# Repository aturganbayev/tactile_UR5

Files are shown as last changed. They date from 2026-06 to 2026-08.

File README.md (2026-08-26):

# Tactile UR5

Automated tactile exploration of silicone breast phantoms ("eggs") using a UR5 robot arm, aiming to **locate an embedded hard "tumor" ball from touch alone**. The pipeline extracts surface geometry from a CAD model, calibrates it to the robot's coordinate frame via ICP, generates approach/press poses over the surface, executes them on the physical (or simulated) robot over a raw URScript TCP socket, and records the contact force (ATI Nano17) synchronized with the TCP pose for each press.

```
cone.STL → surface points → ICP calibration → touch poses → robot execution → force+pose recording
```

Two sensing approaches share that pipeline and are kept deliberately separate:
the **ATI Nano17** on the end-effector pressing the phantom (above), and a
**XELA uSkin tactile pad** on the end-effector recording raw tactile counts
([see below](#xela-tactile-skin-separate-approach)). They have their own pose
grids, recorders and analysis; neither modifies the other.

---

## Hardware

| Component | Details |
|---|---|
| Robot | Universal Robots UR5 (CB2 controller, PolyScope 1.x) |
| Tool | Silicone breast phantom tactile sensor ("egg"), some with an embedded hard ball |
| Tool tip offset | 86 mm along TCP +Z axis |
| Force sensor | ATI Nano17 (SI-50-0.5), serial `FT12876` |
| Force DAQ | NI-DAQ, read via pyForceDAQ (`nidaqmx` backend) |
| Real robot IP | `192.168.0.110` (set as `REAL_HOST` in `pose_utils.py`) |
| Simulation IP | `172.17.0.2` (URSim Docker) |
| Touch-program port | `30002` (secondary client) — used by `run_side_strip_poses.py` so the streamed program does **not** suspend the state broadcast |
| Command / state port | `30003` (single moves like home/start/stop, and the 125 Hz TCP-pose stream the recorder reads) |

---

## Setup

The workstation dependencies are pinned in `requirements.txt`. The `cad_env/`
virtualenv is **not** tracked in git — recreate it from the requirements file:

```bash
# Create and activate the virtualenv, then install dependencies
python3 -m venv cad_env
source cad_env/bin/activate
pip install -r requirements.txt
```

On later sessions just activate it:

```bash
source cad_env/bin/activate
```

**DAQ PC only** — the force + pose recorder in `pyForceDAQ/` additionally needs
`nidaqmx` and `psutil` (uncomment them in `requirements.txt`), the NI-DAQmx
system driver, and `atidaq.so` built from `pyForceDAQ/atidaq_cdll/`. See the
[Force + pose data collection](#force--pose-data-collection-pyforcedaq) section.

### Starting URSim (simulation)

The simulation IP (`172.17.0.2`, `SIM_HOST` in `pose_utils.py`) is the Docker
container's own bridge-network IP, not a host port — so it only matches if
this is the **first** container started on the default bridge network. Start
it, then power it on and release the brakes (also doable through the
PolyScope GUI at `http://localhost:6080/vnc.html`, no VNC client needed):

```bash
docker run --rm -d -p 5900:5900 -p 6080:6080 --name ursim universalrobots/ursim_e-series:latest

# Power on + release brakes via the dashboard server (or click through the
# same steps in the noVNC viewer above):
python3 - <<'EOF'
import socket, time
s = socket.create_connection(("172.17.0.2", 29999), timeout=5)
s.recv(4096)
s.sendall(b"power on\n"); time.sleep(3); print(s.recv(4096))
s.sendall(b"brake release\n"); time.sleep(3); print(s.recv(4096))
EOF
```

If another container already holds `172.17.0.2` (check with
`docker inspect -f '{{json .NetworkSettings.Networks.bridge.IPAddress}}' <name>`
for each container in `docker ps`), start this one on different host ports
(e.g. `-p 5901:5900 -p 6081:6080`) — the internal control ports (30001-30004,
29999) aren't published to the host at all, only reachable via the
container's own bridge IP, so host-port conflicts don't affect the robot
scripts, only the VNC viewer.

---

## Project structure

Scripts are grouped by pipeline stage. Every script resolves data files through
`paths.py`, so they can be run from any working directory (e.g.
`python pose_generation/generate_side_strip_poses.py` from the repo root).

```
tactile_UR5/
├── paths.py              # central path config (single source of truth)
├── pose_utils.py         # shared geometry + motion parameters
├── geometry/             # extract_points.py  (STL → surface points)
├── ur_calibration/       # ICP calibration scripts + their artifacts
├── pose_generation/      # generate_side_strip_poses.py  (surface points → touch poses)
├── execution/            # run_*.py + robot move/stop scripts
├── cone_plots/           # STL point-cloud / normals visualisation
├── pyForceDAQ/            # force + pose recording (ATI Nano17) and press-data analysis
│   └── cone_data/         # sync_cone_data.sh landing spot (gitignored)
├── ur5_tactile_data/      # per-egg recordings + analysis batch scripts (see below)
├── Xela_sensor/           # second, independent sensor approach (see below) - XELA uSkin tactile skin
│   └── palpation/         # pad-based palpation recorder + pose generator
├── data/                  # cone.STL + generated pose CSVs + fixture/mount CAD files
└── figures/               # plot outputs from the CAD/pose pipeline (steps 1-6)
```

---

## Pipeline

### Step 1 — Extract surface points from STL

Samples 3000 points (with surface normals) from the cone CAD model.

```bash
python geometry/extract_points.py
```

**Input:** `data/cone.STL`  
**Output:** `data/surface_points.csv` — columns: `x, y, z, nx, ny, nz` (in mm, STL frame)

---

### Step 2 — (Optional) Visualise the point cloud

```bash
# Plot sampled surface points
python cone_plots/cone_plot.py

# Plot surface points with corrected outward normals
python cone_plots/cone_plot_normals.py
```

**Outputs:** `figures/surface__points_cone_plot.png`, `figures/surface__points_cone_normals_plot.png`

| Point cloud | Surface normals |
|---|---|
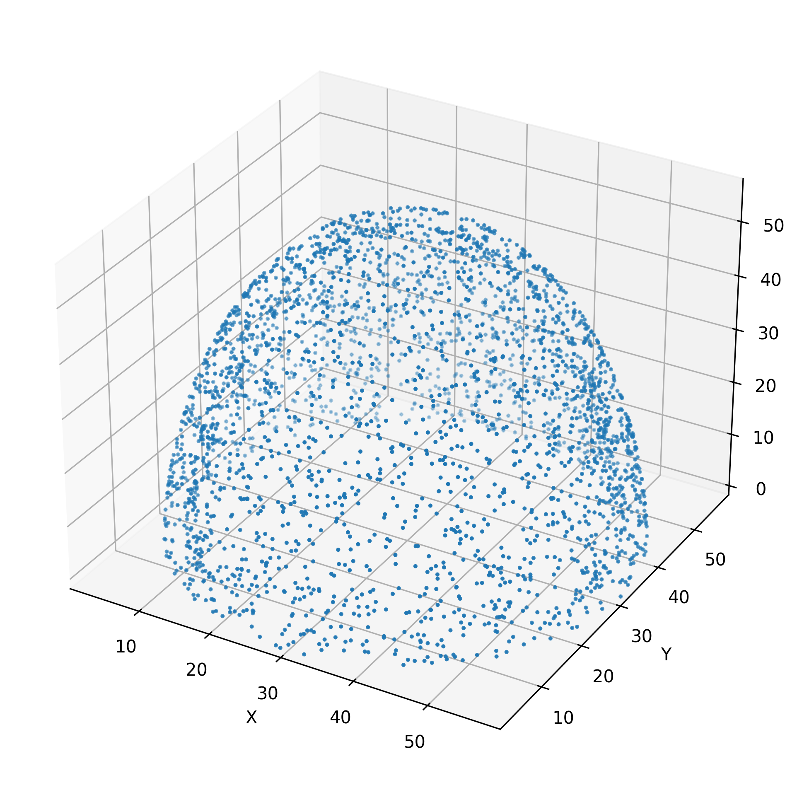
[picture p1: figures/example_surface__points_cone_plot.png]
Surface point cloud
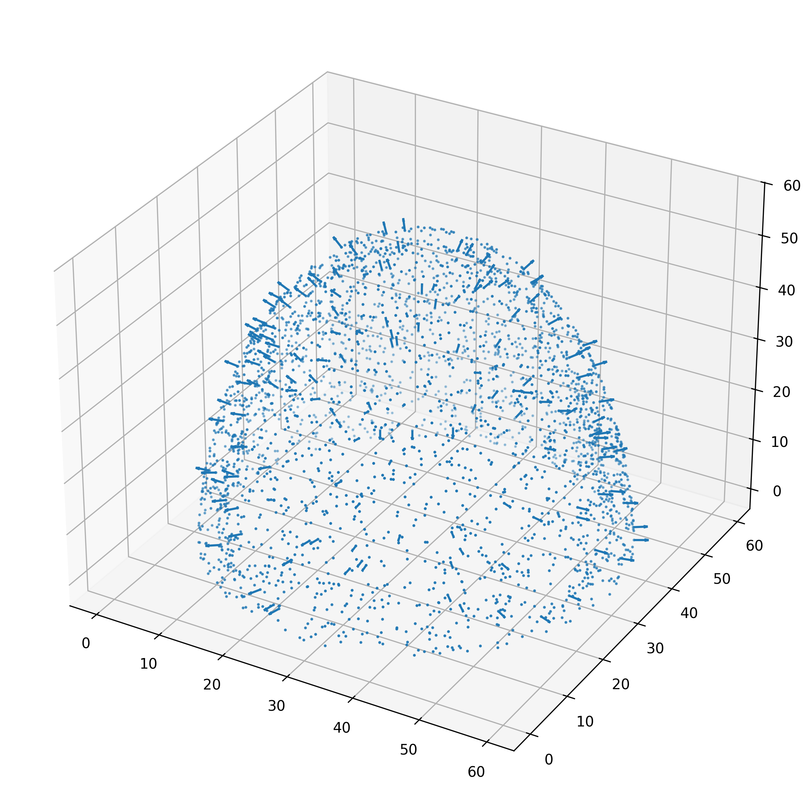
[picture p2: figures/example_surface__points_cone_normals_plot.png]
Surface normals
|  |  |

---

### Step 3 — Record physical calibration points

Interactive CLI. Move the robot so the sensor tip physically touches the cone and read the TCP pose from the teach pendant for each point.

```bash
python ur_calibration/record_icp_points.py
```

- **Point 1 must be the cone apex** (top).
- Record 10–15 more points spread around the upper sides.
- Enter each pose as `x y z rx ry rz` (mm or m — auto-detected; radians for rotation).
- Type `done` when finished.

**Output:** `ur_calibration/physical_points.csv` — columns: `x_tcp, y_tcp, z_tcp, rx, ry, rz, x, y, z`

---

### Step 4 — Run ICP calibration

Aligns the STL point cloud to the robot base frame using the physical touch points as ground truth.

```bash
python ur_calibration/calibrate_icp.py
```

**Constrained to a vertical axis.** The calibration **pins the cone axis to the robot base +Z** and fits only the position (translation-only ICP). The reason: the calibration touch points all sit near the apex (top ~half of the cone), which barely constrains the axis *orientation* — a free ICP latches onto noise and produces a spurious ~20° tilt, making an upright cone look leaning in the base frame. Since the cone physically stands upright on a level surface, fixing the axis vertical removes that artifact and actually fits the points slightly better (RMS ≈ 2.2 mm vs 2.5 mm for the free fit on the original dataset; a careful 13-point recalibration reaches ~1.5 mm RMS). Rotation about the vertical is irrelevant for a surface of revolution, so it is left at identity.

> This assumes the robot base is mounted vertical and the cone sits on a level surface. If your base is genuinely tilted, restore a free ICP instead.

**Inputs:** `data/surface_points.csv`, `ur_calibration/physical_points.csv`, `data/cone.STL`  
**Outputs:**
- `ur_calibration/icp_transformation_matrix.txt` — 4×4 STL-to-robot transform (rotation = identity, i.e. cone upright)
- `ur_calibration/surface_points_base.csv` — surface points (with normals) in robot base frame (meters)

Calibration quality (mean/RMS/max error in mm) is printed on completion. Target: mean error < 5 mm.

---

### Step 5 — Validate calibration

Re-checks alignment by projecting recorded physical contact points onto the calibrated mesh.

```bash
python ur_calibration/validate_calibration.py
```

**Inputs:** `ur_calibration/physical_points.csv`, `ur_calibration/icp_transformation_matrix.txt`, `ur_calibration/surface_points_base.csv`  
Re-run `ur_calibration/calibrate_icp.py` if mean error exceeds 5 mm.

---

### Step 6 — Generate touch poses

Generates `NUM_STRIPS` vertical strips evenly distributed around the cone, each with `NUM_POINTS` touch points from near the apex down to `MIN_HEIGHT_FRACTION` of the cone height. All work is done in the cone's own axis frame (the vertical axis established during calibration). This is the only pose generator in the pipeline — pressing every one of the ~3000 sampled surface points isn't realistic, so only the evenly-spaced strip grid is generated and executed.

Each contact point is **synthesized directly on the strip's meridian** rather than picking the nearest measured point. Because the cone is a surface of revolution, this gives:

- **Straight strips** — every point of a strip sits at exactly the strip's azimuth, so the strip traces a clean line down the cone (no zig-zag from discrete sampling).
- **Even spacing, apex included** — target heights are evenly spaced including both endpoints, so the first point of every strip lands exactly on the true apex (instead of being offset by half a band width); the local cone radius still comes from a linear fit of the points within each height band.
- **Clean normals** — the surface normal is taken from the nearest measured point, projected into the meridian plane and forced outward (handles the apex too).

To keep the printed sensor holder clear of the cone and the wrist clear of the lower arm, the tool orientation is tilted toward vertical with a height-scaled magnitude: `MIN_ORIENTATION_TILT_DEG` (7°) at the apex band up to `MAX_ORIENTATION_TILT_DEG` (14°) at the lowest band. **Only the orientation tilts** — the contact point and press direction stay on the true surface normal — so the press stays near-perpendicular (≈5–15° off-normal). The applied tilt is recorded per pose in the `tilt_deg` CSV column.

**Apex orientation matches its strip's azimuth.** At the true apex the outward normal points straight up the cone axis, so azimuth has no local meaning there. `normal_to_rotvec()` in `pose_utils.py` resolves this case with a `y_hint`: the generator passes the strip's meridian-perpendicular direction, so the apex point's frame stays consistent with every other point in its strip. Descending a strip, the tool orientation therefore changes smoothly in pitch only — azimuth is constant top to bottom.

```bash
python pose_generation/generate_side_strip_poses.py
```

**Output:** `data/cone_touch_poses.csv` (with `strip`, `strip_angle_deg`, `tilt_deg` columns), `figures/cone_touch_poses.png`

The plot has two panels: a **3D view** (robot base frame) and a **top-down view** along the cone axis (good for checking the strips are evenly distributed around the circle).

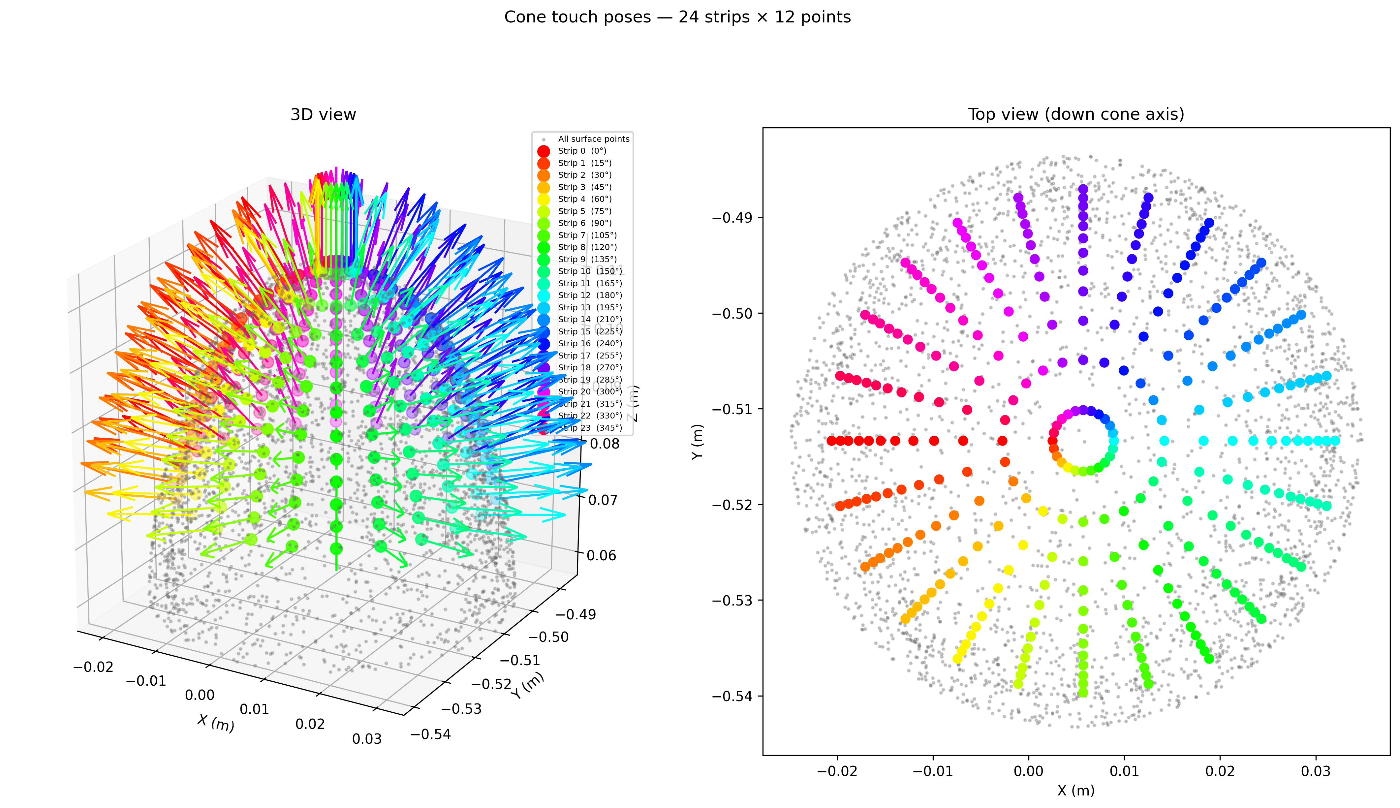
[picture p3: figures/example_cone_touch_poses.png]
Cone touch poses


Key parameters, defined as tunable constants at the top of the script (see the comments there for current defaults):

| Parameter | Description |
|---|---|
| `NUM_STRIPS` | Strips evenly distributed around the cone |
| `NUM_POINTS` | Touch points per strip (top → bottom) |
| `MIN_HEIGHT_FRACTION` | Lower bound of the strips (fraction of cone height). Lower it for more lower-cone coverage, at the cost of clearance (arm config keeps the wrist joints off the table, esp. on the near side toward the robot base). |

Both `NUM_STRIPS` and `NUM_POINTS` are free to change; the generator and executor adapt automatically. Each row in the pose CSV contains a paired approach pose (`approach_distance` = 15 mm stand-off along the surface normal) and a press pose (`press_distance` = 15 mm into the surface).

---

### Step 7 — Move robot to start pose

Moves the robot through a safe pre-pose to the hover position directly above the cone apex (30 mm clearance).

```bash
python execution/home_start.py
```

Prompts for `sim` or `real` mode. Motion sequence:

```
movej → Pre-pose [-π/2, -π/2, -π/2, -π/2, π/2, -π/2]
   └─ movel → Start pose (apex TCP + 30 mm Z)
```

To move directly to the start pose only (skipping the pre-pose joint move):

```bash
python execution/start_pose.py
```

To move to *only* the pre-pose joint configuration (skipping the movel to the
cone's start pose entirely) — e.g. as a safe, cone-independent waypoint
before positioning the robot for other work (such as the XELA calibration
rig, see below):

```bash
python execution/go_pre_pose.py
```

---

### Step 8 — Execute touch sequence

Streams the full URScript program to the robot. For each pose: transit to approach → press → retract. Prompts for `sim` or `real`. The robot returns to the start pose after all touches complete.

```bash
python execution/run_side_strip_poses.py
```

Motion strategy (`execution/run_side_strip_poses.py`):

- **Inverse kinematics is solved in software** (`ur5_ik_near` in `pose_utils.py`, validated UR5 FK/IK) for every pose, seeded from the previous solution within a strip and reset to the start config between strips — this both validates reachability (unreachable poses are flagged and skipped) and keeps a chained seed ready for the next strip's entry `movej`. The controller's `get_inverse_kin` is *not* used: it does a single Newton solve from one fixed seed, which cannot converge for poses spread all the way around the cone, leaving the arm reorienting without reaching the points.
- **Only the first point of each strip transits in joint space** (`movej([j1..j6])`) — that's the big swing from the start pose all the way around to the strip's azimuth, which needs the offline IK solve above.
- **Every other transit within a strip uses `movel`** to the precomputed Cartesian approach pose, at the slow contact speed (`*_approach_*`, same as the press itself) — consecutive points are millimetres apart and share the same azimuth (see apex-orientation note above), so a straight-line Cartesian move keeps the tool orientation locked to that azimuth the whole way.
- **Press and retract use `movel`** — short, controlled linear motion along the surface normal, at the slow contact speed (`*_approach_*` in `pose_utils.py`).
- **Between strips the tool lifts straight up** (`SAFE_LIFT_M` = 60 mm, base +Z) *before* the joint-space swing back to the start pose, so the `movej` arc cannot graze the cone (which otherwise registers a false press).
- **Settle pauses are mode-dependent** (`SETTLE`): 0.1 s in sim, 1 s on real.
- Each transit logs a **1-based** `pose`/`strip`/`point` identifier via `textmsg` (e.g. `pose 13 strip 2 point 1`) — visible in the PolyScope Log tab to identify the failing pose after a protective stop. `pose` numbering matches the 1-based press numbering `record_cone_press.py` writes, so a specific press can be traced back to the exact strip/point that produced it (the underlying `strip` column in the pose CSV itself stays 0-based).

> **Note on speeds:** `V_sim`/`A_sim`/`V_real`/`A_real` (joint speed/accel, rad/s and rad/s²) apply only to the once-per-strip entry `movej`; every within-strip transit, press, and retract moves at the `*_approach_*` linear speed/accel (m/s, m/s²) instead. Sim's transit values are pushed near the UR5 joint limit since there's no hardware to protect.

> **Horizontal rotation happens only at strip entry.** Because the apex sits on the cone's axis, the arm's *position* barely changes between strips, so the azimuth change between one strip and the next is carried almost entirely by wrist_3 — visible as the tool spinning in place right before descending into the new strip. This entry swing happens in free space, before any contact with the phantom, so it never affects press data; once inside a strip the tool holds a constant heading and only pitches over as it descends.

> **Real-robot caveat:** the software IK uses the *ideal* UR5 DH parameters, which match URSim exactly. On hardware the calibrated DH differs by ~mm, so a joint-commanded approach (a hover point) may land a few mm off — harmless, and the `movel` press still hits the correct Cartesian target. Always dry-run in sim first.

---

### Step 9 — Return to home

```bash
python execution/go_home.py
```

Sends a single `movej` command to the home configuration `[0, -π/2, 0, -π/2, 0, 0]`.

---

## Force + pose data collection (pyForceDAQ)

Records ATI Nano17 force synchronized with the UR5 TCP pose while the robot presses the cone. Each press is auto-detected from the force signal, and its **peak force** is logged together with the TCP pose at that instant. The recorder runs on the PC the NI-DAQ is connected to, in parallel with any of the `run_*.py` motion scripts.

Force comes from the Nano17 (far more accurate than the robot's built-in TCP-force estimate); the TCP pose is read from the UR real-time stream on port `30003`. Both are sampled in one loop so they share a single timestamp.

### One-time setup (on the DAQ PC)

```bash
# 1. Build and install the ATI calibration C library
cd pyForceDAQ/atidaq_cdll && make atidaq.so
sudo cp atidaq.so /usr/lib/atidaq.so

# 2. Install the NI-DAQ Python backend (requires the NI-DAQmx driver)
pip install nidaqmx

# 3. Install plotly (renders the live trajectory/press view; see "Live plot" below).
# Without it, record_cone_press.py prints a warning and keeps recording fine,
# just without the live HTML view.
pip install plotly
```

The sensor calibration file `pyForceDAQ/calibration/FT12876.cal` (the Nano17) is tracked in git, so a fresh checkout already has it. If your transducer has a different serial, drop its ATI `.cal` into `pyForceDAQ/calibration/` and update `SENSOR_NAME` in `record_cone_press.py`.

### Record

Two terminals on the DAQ PC:

```bash
# Terminal 1 — recorder (keep hands off the sensor during bias)
cd pyForceDAQ
python3 record_cone_press.py
# No sim/real prompt - this reads a physical Nano17 over NI-DAQmx, so there is
# nothing to record against URSim; it always uses REAL_HOST.
# Prompts for:
#   * the expected number of presses (blank to skip) - so a short file is
#     reported outright rather than discovered later
#   * the egg name: e.g. "red_mid" -> cone_data/red_mid/, or "none" for
#     cone_data/ directly.

# Terminal 2 — motion that presses the cone
python3 execution/run_side_strip_poses.py
```

Each detected press prints live (`Press N: peak Fz = … at TCP=[…]`) and also updates a **live 3D view** of the TCP path over the cone surface: a small local HTTP server (started automatically, default port `8765`, first free port at/after that) serves a page showing the cone surface (dark gray), the TCP path so far (black), and a red diamond + label (`#N <peak Fz>N`) at each detected press. The page polls a JSON file every `LIVE_PLOT_REFRESH_S` (default `0.5` s) and updates the plot **in place** with Plotly's `Plotly.react()` — unlike a page reload, this does not reset your pan/zoom/rotation, and the update is skipped entirely while you're dragging to rotate (so rotating the view stays smooth) or when the underlying data hasn't changed. The axis range is computed once from the calibrated cone surface (plus a margin) rather than auto-fit to the growing trajectory, so the camera has a stable frame to rotate around instead of fighting a rescaling view every poll.

By default it does **not** open a browser on the recording machine (`LIVE_PLOT_AUTO_OPEN = False`) — every run instead prints every reachable LAN URL (probed toward the robot's subnet first, since that's the network the viewing machine is normally on, then the machine's default route) to open from another machine:

```
Live plot - open from any machine on the same network:
  http://<this machine's IP>:8765/live_view.html
```

This matters in practice: WebGL (which Plotly's 3D plots need) often has no real GPU acceleration on a DAQ PC, and Chrome will visibly stall there (`GPU stall due to ReadPixels` in its logs) regardless of how few points are plotted — view it from a machine with a real GPU instead. Set `LIVE_PLOT_AUTO_OPEN = True` if you're recording on a machine with working GPU acceleration and do want it to also open locally.

The cone surface comes from `ur_calibration/surface_points_base.csv`, which is gitignored (regenerated by `calibrate_icp.py`) — a checkout that never ran calibration locally (e.g. a DAQ PC that only records, while calibration was done on the workstation) won't have it. Without it, the live plot still works but without the cone for scale/reference, and a warning is printed; copy the file over manually (e.g. through the same sshfs mount `sync_cone_data.sh` uses) if you hit this.

The HTML is rendered by a background thread that only ever takes a quick snapshot of the trajectory/press buffers — a slow render just makes the file update less often, it can never add lag to the 125 Hz DAQ loop. If `plotly` isn't installed it disables itself automatically with a warning; CSV recording is unaffected either way. Press `Ctrl-C` to stop the recorder once the motion finishes — the file is updated once more with the final state. Outputs are written to `cone_data/<egg name>/` (or `cone_data/` directly if you typed `none`), timestamped per session:

| File | Contents |
|---|---|
| `<ts>_trajectory.csv` | Continuous `t, x,y,z,rx,ry,rz, speed, Fx,Fy,Fz, Fmag` (~125 Hz) |
| `<ts>_presses.csv` | One row per detected press: peak `Fz` / `\|F\|` and the TCP pose at the peak |

**Press detection** thresholds on **`Fmag` = |F|** (not signed `Fz`) — a touch near the cone's embedded bulge can load mostly `Fx`/`Fy` with `Fz` negative, missing a `Fz`-only threshold even though `|F|` is well above it. A press starts once `Fmag` rises above `PRESS_ON_N` (`0.3 N`) and is only considered over once `Fmag` has stayed below `PRESS_OFF_N` (`0.15 N`) for `PRESS_OFF_DEBOUNCE_S` (`0.5 s`) — long enough to ride out the momentary dip some cones show between the soft outer shell and an embedded hard "tumor" ball, which would otherwise look like two separate presses. Thresholds sit well above the sensor noise floor (~0.03 N) but low enough to catch shallow contacts — a press over a high point of a phantom can peak at only ~0.4 N if the calibrated surface sits a couple of mm off.

After a press ends, new presses are ignored for `PRESS_REFRACTORY_S` (`1.5 s`) to filter out the rebound as the tool retracts. This window must stay **below the shortest real press-to-press gap** (~2.6 s at the current approach speeds), since a longer window would swallow weak presses outright and clip the impact peak off presses that start inside it.

**Speed gate against transit false-positives:** lowering the force threshold to catch shallow real presses also makes the detector sensitive to brief transit contacts — grazing the cone during a between-strip swing, or the tacky silicone momentarily sticking to the retracting tip. Both happen entirely while the tool is moving; a real press always contains the ~1 s stationary hold at the pressed position. A candidate press is only recorded if at least one in-contact sample had TCP speed ≤ `PRESS_HOLD_SPEED_MS` (`0.01` m/s); otherwise it's dropped and logged as `[info] ignored moving contact`.

**Contacts that are NOT recorded are announced.** Four things can silently
drop a press, and a run that looks clean can still be short — recording
`blue_mid` produced **284 presses for 288 commanded poses** with nothing on
screen to say so. The two causes turned out to be different, and both are now
reported as they happen and totalled at the end:

```
[MISSED] contact peaked at 0.28 N, below PRESS_ON_N=0.3 - NOT recorded
[MISSED] contact of 1.41 N suppressed by the 1.5 s refractory window - NOT recorded
[MISSED] moving contact of 0.87 N ignored - tool never stationary - NOT recorded
Press 183: peak Fz = 1.39 N ...
         ^ WARNING: that press contained 3 force bumps - it may have merged two presses
```

The merge warning matters as much as the threshold ones: `PRESS_OFF_DEBOUNCE_S`
exists to ride out the bimodal shell-then-ball curve, but it also bridges
genuinely separate presses, which is how `blue_mid` lost two poses whose force
was 1.41 N and 1.49 N — well above any threshold.

If you enter an expected press count at startup, a short file is stated
outright:

```
*** 284 of 288 expected presses - 4 MISSING ***
    Press numbering is now offset from pose numbering after each gap.
    Align by position against the pose CSV before comparing runs.
```

That last point is the one to watch: after a gap, `presses.csv` row *k* is no
longer pose *k*, so anything comparing specimens by row index is silently
misaligned from there on.

Logged at `LOOP_HZ` = 125 Hz.

**DAQ sample rate:** the Nano17 runs in HW-timed single-point mode, so the host must service the device every sample; too high a rate overruns the DAQ buffer (NI error `-200714`). `SENSOR_RATE` (default `500` Hz) keeps comfortable headroom over the 125 Hz logging loop. Lower it (e.g. `250`) if the overrun recurs on a loaded machine.

### Visualize a single recording

```bash
python pyForceDAQ/plot_cone_data.py [stamp]
```

`stamp` is the timestamp prefix of a recording (matches `<stamp>_trajectory.csv` / `<stamp>_presses.csv` in `pyForceDAQ/cone_data/`); if omitted, the most recently modified recording is used. Saves five PNGs to `figures/` (and shows them):

| File | Contents |
|---|---|
| `<stamp>_force_vs_time.png` | `Fz`/`\|F\|` over time, with detected press peaks marked |
| `<stamp>_speed_vs_time.png` | TCP speed over time |
| `<stamp>_trajectory_3d.png` | 3D approach paths into each press, the top 24 by peak force highlighted in gold and the next 24 in cyan (free-space transit between strips is filtered out) |
| `<stamp>_peak_force_per_press.png` | Peak `Fz`/`\|F\|` bar chart, one bar per press |
| `<stamp>_press_force_on_cone.png` | Peak force at each press mapped onto the calibrated cone surface, top/next-24 marked with star/triangle markers |

The same module also exposes `save_trajectory_3d_html` / `save_press_force_on_cone_html`, which render the equivalent interactive WebGL plots (Plotly) to standalone `.html` files. For batch use across a whole data folder, see [Per-egg data](#per-egg-data-ur5_tactile_data) below.

### Sync recordings from the DAQ PC

`sync_cone_data.sh` copies recordings from the DAQ PC (mounted via sshfs at `~/remote-server`) into this repo's `pyForceDAQ/cone_data/`. Run it on the workstation:

```bash
~/github_local/tactile_UR5/pyForceDAQ/sync_cone_data.sh          # one-shot copy
~/github_local/tactile_UR5/pyForceDAQ/sync_cone_data.sh --watch  # auto-copy every 10s
```

Copy is the default (originals kept; safe to run while a session is recording). `--watch [SECS]` polls on an interval; `--move` deletes the source files after copying. It mirrors the DAQ PC's folder structure recursively, so a per-egg subfolder recorded via the name prompt lands as `pyForceDAQ/cone_data/<egg name>/`. The batch plot script operates on `ur5_tactile_data/`, so **move or copy each synced egg folder from `pyForceDAQ/cone_data/` into `ur5_tactile_data/`** once it's synced, before running it below.

---

## Per-egg data (`ur5_tactile_data/`)

Recordings, one subfolder per egg, live in `ur5_tactile_data/` in this repo (not `~/ur5_tactile_data` — that location is deprecated). `empty/` is the reference phantom: the same body with no ball inside, pressed over the identical pose grid.

```
ur5_tactile_data/
├── plot_cone_data_batch.py    # raw force/trajectory plots, per egg
├── empty/                     # reference phantom (no ball)
│   └── <ts>_trajectory.csv, <ts>_presses.csv
├── red_mid/
│   └── ...
└── ...
```

`plot_cone_data_batch.py` walks every subfolder here, so a new egg folder (recorded, then synced/copied in as above) is picked up automatically — nothing needs to be registered by hand. It writes its outputs back into the egg's own subfolder, named `<egg>_<plot>.png`/`.html`.

---

## XELA tactile skin (separate approach)

A second, independent sensing approach alongside the cone/Nano17 pipeline
above: a XELA Robotics uSkin tactile pad mounted on the **UR5 end-effector**
and pressed against the phantom, recording **raw tactile counts** — there is no
force calibration and none is needed, since both the stop criterion and the
comparison between specimens are relative. Kept fully separate by design —
every script here is new; nothing in `pyForceDAQ/` is modified.

```
Xela_sensor/
├── xela_server, xela_viz, xela_log, xela_conf   # XELA's own compiled binaries (v1.7.8b)
├── xServ.ini              # sensor config (working config below)
├── xServ_sim_backup.ini   # original simulation-mode config, kept as a backup
└── palpation/
    ├── xela_palpation.py     # the recorder: walks a pose grid, presses each to a tactile target
    ├── make_xela_poses.py    # pad-sized pose grid generator (+ footprint plot)
    ├── measure_pad_axes.py   # one-off: measure the pad's axes in the tool frame
    ├── rederive.py           # re-derive results at a different target, offline
    └── data/                 # recordings land here
```

### Hardware / software

| Component | Details |
|---|---|
| Sensor | XELA Robotics uSkin, model **XR1944** (16 taxels in a 4×4 grid at 5 mm pitch, 24×28 mm pad), microcontroller ID **3** |
| Interface | ESD CAN-USB/2, socketcan (`can0`), 1 Mbit/s |
| Server | XELA's own `xela_server` binary (v1.7.8b), broadcasts JSON over WebSocket (`ws://<ip>:5000`) |
| Data | Raw, **uncalibrated** 16-bit X/Y/Z counts per taxel — this sensor generation has no native force calibration in XELA's own software (only uSPa22/44/46 do) |
| Module limit | 10 N / 25 kPa normal, **scaling with contact area** — the manual is explicit that half-surface contact means half the force |

### Bringing the sensor up

```bash
sudo ip link set up can0 type can bitrate 1000000   # once per boot/replug (or via the udev rule below)
cd Xela_sensor
./xela_server -f xServ.ini --ip 0.0.0.0 -l xela_server.log
cansend can0 203#07.00                                # manual start trigger - this old-protocol sensor doesn't auto-stream
./xela_viz -f xServ.ini                               # optional live visualisation
```

Stop the stream with `cansend can0 203#07.01`. The current `xServ.ini`
(`bustype = socketcan`, `channel = can0`, `model = XR1944`, `version = 1`,
`id = 3`) reflects several non-obvious fixes: `version = 1` is required for
this old CAN-ID layout (the newer default, `version = 3`, silently maps zero
taxels), and `--ip 0.0.0.0` is needed because this build otherwise binds only
the machine's LAN IP, leaving `xela_viz`/localhost clients with no data. The
`[viz]` section is also tuned (`arrows = full`, `origins = on`,
`transparency = on`) — note the shipped defaults wrote comments *after* values
on the same line, which Python's `configparser` does not strip by default, so
those settings may never have taken effect.

### Pose grid

`make_xela_poses.py` generates poses sized for the **pad**, not for a point
tip. The cone grid (`cone_touch_poses.csv`, 288 poses) was built for the
Nano17's 0.7 mm indenter — consecutive poses sit 0.8 mm apart, which for a
24×28 mm pad means re-measuring the same contact patch over and over. This
generator instead places rings spaced by pad footprint down the slant, with
`circumference / spacing` poses in each ring, so coverage adapts to the taper.

```bash
python3 Xela_sensor/palpation/make_xela_poses.py
```

**Output:** `data/xela_poses_nano17reg.csv` (23 poses in 3 rings, ~53% pad
overlap at 12 mm spacing), plus `figures/xela_poses_nano17reg.png` showing the
actual pad footprints — the overlap and the overhang past the phantom edge are
invisible from centre markers alone.

Two things it does that the point-tip generator does not:

- **Wrist-3 minimisation.** `normal_to_rotvec` ties the tool yaw to the ring
  azimuth, so a ring sweeping 0→360° spins J6 a full turn; four rings
  accumulated **~1400° in one direction**, which both exceeds the ±360° joint
  limit and wraps the sensor cable four times. Rotation about the press axis
  carries no information here (the pad is read as a whole-pad scalar), so the
  generator searches that spin per pose and keeps whichever puts J6 nearest
  neutral: **1400° → 59°**.
- **A higher floor.** `MIN_HEIGHT_FRACTION = 0.65` versus the cone grid's 0.45.
  The binding constraint is not the contact height but the **pad edge**: the
  pad reaches ~14 mm past its centre, so at the 14° tilt used low down its
  lower edge sits ~10 mm below whatever it touches. At 0.50 the lowest ring hit
  the platform and every one of its poses "reached target" in 2–4 mm.

### Recording

```bash
python3 Xela_sensor/palpation/xela_palpation.py
```

Prompts for `sim`/`real` and a **specimen name**; writes `<name>.csv` (the full
trajectory) and `<name>_summary.csv` (one row per pose). An existing name is
never overwritten — repeats become `<name>_2`, `<name>_3`.

At each pose it settles, takes a per-pose baseline, approaches until the
taxels register contact, then presses until the **total** response across all
16 taxels reaches `TARGET_TOTAL_COUNTS`. Motion is continuous rather than
stepped: one slow `movel` that the sensor interrupts with `stopl()`, so
overshoot is latency × speed (~0.4 mm) instead of a step size.

**Why total and not peak.** Peak is a single-taxel reading, so any corner
touching hard ends the press regardless of how little of the pad is loaded. In
one run every pose reported "1400 peak counts" while the actual load spanned
**3187–11337** — a 96% spread, and those are not comparable measurements. On
the total criterion the same 23 poses land within **1.2%** of each other.

Useful flags:

| Flag | Effect |
|---|---|
| `--check` | Offline reachability + joint-limit + cable wind-up check. No robot, no sensor. |
| `--monitor` | Live per-taxel readout with running maxima. No robot motion. |
| `--motion-only` | Visit approach poses without pressing — for URSim, where there is nothing to touch. |
| `--limit N` | First N poses only. |
| `--target-total N` | Override the stop target. |

**Outcome per pose** (`reason` in the summary): `ok` (reached target),
`travel_cap` (18 mm, still climbing), `over_range` (a taxel hit 2200 counts —
recorded and the sweep continues), `no_contact`, `xela_stalled`. A pose whose
response stops growing is *flagged* (`went_flat`) but never stopped — stopping
on it made marginal poses bistable, reporting 485 counts on one run and 1418 on
the next for the same physical egg.

### Re-deriving at a different target

Every press is logged continuously, so a run recorded at one target still
contains everything needed to answer "where would it have stopped at a lower
one?".

```bash
python3 Xela_sensor/palpation/rederive.py --target 4000
```

This matters: 8000 was originally chosen from a firm specimen and turned out to
need 14–17 mm on soft ones, where the UR5's own protective stop engaged. The
whole set was re-derived at 5000 without touching the robot. **Keep the
trajectory CSVs** — the summaries alone cannot do this.

### What was tried and rejected

Recorded here so it is not repeated:

- **Converting counts to Newtons at all.** Per-taxel calibration is not
  achievable on this sensor — cross-talk spreads load to neighbours above
  ~1–1.5 N — and a whole-pad model caps at ~0.66 N RMS with a flat learning
  curve, so more data does not lift it. Palpation therefore works in **raw
  counts**, which is sufficient: the stop criterion and the comparison between
  specimens are both relative.
- **Re-aiming the pad to centre the contact** — the mechanism works (it centres
  by the predicted amount once the pad-axis mapping is measured rather than
  assumed), but outcomes got **worse**: mean peak 1218 → 991 over the same four
  poses. The correlation that motivated it was confounded — where the pad
  happens to sit flat it gets both a central contact and good loading, and
  tilting to force centring does not create flatness. Kept behind `--adapt`,
  off by default.

---

## Video demo

Video demo (https://www.youtube.com/watch?v=YsXVEiOJwH0)

---

### TCP pose utilities (real robot)

Read the current TCP pose, or jog the robot to a given pose. Both use the same
format — 6 space-separated values, `x y z` in **mm** and rotation vector
`rx ry rz` in **rad** (base frame) — so a printed pose can be pasted straight
back as a move target.

```bash
# Print the current TCP pose as a single line, e.g.
#   2.490 -513.500 211.850 -2.200000 2.200000 0.000000
python execution/print_tcp_pose.py

# Move the TCP to a pose (prompts for it, or pass as arguments).
# Confirms before sending, then does a linear movel from the current pose
# at the slow approach speed.
python execution/move_to_pose.py [x y z rx ry rz]
```

> `move_to_pose.py` moves **linearly** from wherever the robot is — the path
> doesn't know about the cone, so don't command a pose on its far side.

---

### Emergency stop

Immediately decelerates and stops the robot (does not require mode selection).

```bash
python execution/stop_robot.py
```

Sends `stopl(2.5)` directly to the real robot (`REAL_HOST` in `pose_utils.py`, `192.168.0.110`).

---

### Shutdown

Returns to the home configuration, then powers down the real robot controller. Requires typing `yes` to confirm before sending.

```bash
python execution/shutdown_robot.py
```

---

### Live monitoring (CB2 controllers)

This robot is a **CB2** controller (PolyScope 1.x) — it has no Dashboard Server (introduced in CB3), so there's no scripted way to read robot state/logs through that interface. The pendant's Log tab is fed live from a Robot Message stream on the **Primary client interface (port 30001)**; the on-disk log file (`/root/log_history.txt` on the controller) is only flushed at boot/shutdown boundaries, so tailing it over SSH misses everything in between, including `textmsg()` calls from a running program.

`watch_robot_messages.py` connects directly to port 30001 and decodes that live stream, mirroring what the pendant shows in real time (mode changes, protective/E-stop events, and the per-pose `textmsg` calls from `run_side_strip_poses.py`):

```bash
python execution/watch_robot_messages.py
```

Prompts for `sim`/`real`. Streams to the terminal and also saves to `execution/robot_logs/<timestamp>_messages.log`. Ctrl-C to stop. Run it in a separate terminal alongside any motion script to track progress and catch a protective stop the instant it happens.

---

## File Reference

| File | Description |
|---|---|
| `requirements.txt` | Pinned workstation dependencies; recreate the venv with `pip install -r requirements.txt` |
| `paths.py` | Central path config — absolute locations of all data files; imported by every script |
| `pose_utils.py` | Geometry helpers (TCP↔contact conversion, normal→rotation vector, orientation tilt), **UR5 forward/inverse kinematics** (`ur5_fk`, `ur5_ik_near`) used for offline IK, and shared motion parameters (speeds, distances, tilt limits) |
| `data/cone.STL` | CAD model of the silicone cone tool |
| `data/egg_holder_4_revolvehole-3mm.SLDPRT` / `.STL` | SolidWorks part + STL export for the egg holder fixture (current revision; ~95×86×95mm bounding box) |
| `data/xela_sensor_mounted.SLDPRT` / `.STL` | SolidWorks part + STL export of the mount attaching the XELA sensor to the **UR5 end-effector** (~99.5×59×80.7mm bounding box) |
| `data/xela_sensor_breadboard_mount.SLDPRT` / `.STL` | Mount attaching the XELA sensor to the **optical breadboard/platform** (~70×59×70mm bounding box). Unused by the current pipeline, which mounts the pad on the end-effector — kept for bench tests against a fixed sensor |
| `data/tip_touch_li_0.7.SLDPRT` / `.STL` | Sharper indenter tip (~21×34×21mm bounding box) — a narrower alternative to the standard cone-press tip |
| `geometry/extract_points.py` | Sample surface points and normals from STL |
| `cone_plots/cone_plot.py` | Visualise sampled surface point cloud |
| `cone_plots/cone_plot_normals.py` | Visualise surface points with corrected outward normals |
| `ur_calibration/record_icp_points.py` | Interactively record physical touch points from the teach pendant |
| `ur_calibration/calibrate_icp.py` | Align STL to robot base frame — axis pinned vertical, translation-only fit (avoids the spurious tilt a free ICP gets from apex-clustered points) |
| `ur_calibration/validate_calibration.py` | Verify calibration quality against recorded points |
| `pose_generation/generate_side_strip_poses.py` | Generate poses for multiple strips around the cone, top to bottom |
| `execution/run_side_strip_poses.py` | Execute side strip touch sequence on the robot |
| `execution/home_start.py` | Move robot through pre-pose to start pose |
| `execution/start_pose.py` | Move robot directly to start pose |
| `execution/go_pre_pose.py` | Move robot to the pre-pose joint configuration only (cone-independent waypoint) |
| `execution/go_home.py` | Return robot to home configuration |
| `execution/print_tcp_pose.py` | Print the real robot's current TCP pose (one line: `x y z` mm + `rx ry rz` rad) |
| `execution/move_to_pose.py` | Move the real robot's TCP to an input pose (same format; confirms, then slow linear move) |
| `execution/stop_robot.py` | Emergency stop |
| `execution/shutdown_robot.py` | Return home, then power down the real robot controller (requires typing `yes` to confirm) |
| `execution/watch_robot_messages.py` | Live-decode the Robot Message stream (port 30001) — mirrors the pendant's Log tab in real time |
| `pyForceDAQ/record_cone_press.py` | Record Nano17 force + UR5 TCP pose; auto-detect each press (with a speed gate against transit false-positives) and log its peak force with the pose at that instant; prompts for an egg name to record into a per-egg subfolder |
| `pyForceDAQ/plot_cone_data.py` | Plot one recorded session: force/speed over time, 3D approach paths and peak-force-on-cone-surface (top presses by force highlighted); also exposes interactive Plotly HTML variants |
| `pyForceDAQ/sync_cone_data.sh` | Copy recordings from the remote DAQ PC (sshfs mount) into `pyForceDAQ/cone_data/` |
| `pyForceDAQ/calibration/` | ATI sensor calibration files (`FT12876` = Nano17, `FT12877`) |
| `ur5_tactile_data/plot_cone_data_batch.py` | Batch-run `plot_cone_data.py`'s plots over every egg folder here; skips recordings whose plots are already up to date |
| `Xela_sensor/xServ.ini` | XELA server config for this sensor (`socketcan`/`can0`, model `XR1944`, `version = 1`, `id = 3`) |
| `Xela_sensor/xServ_sim_backup.ini` | Original simulation-mode config, kept as a backup |
| `Xela_sensor/palpation/xela_palpation.py` | Walk a pose grid pressing each pose to a total tactile-count target; continuous sensor-interrupted motion, per-pose baseline, stall detection; `--check` / `--monitor` / `--motion-only` |
| `Xela_sensor/palpation/make_xela_poses.py` | Pad-sized pose grid (rings spaced by footprint) with wrist-3 minimisation; also writes the pad-footprint plot |
| `Xela_sensor/palpation/measure_pad_axes.py` | One-off: tilt a known amount on a flat surface to measure which tool axis each taxel-grid axis maps to |
| `Xela_sensor/palpation/rederive.py` | Re-derive per-pose results at a different count target from recorded traces — no robot needed |
| `Xela_sensor/palpation/data/` | Palpation recordings (`<specimen>.csv`, `<specimen>_summary.csv`) |
| `ur_calibration/record_icp_points_xela.py` | Record ICP points using the pad as the probe: descends until the taxels register contact, corrects for where on the pad the touch landed |
| `data/surface_points.csv` | Raw STL surface points (mm, STL frame) |
| `ur_calibration/surface_points_base.csv` | Surface points in robot base frame (m) |
| `ur_calibration/physical_points.csv` | Recorded physical touch points from teach pendant |
| `ur_calibration/icp_transformation_matrix.txt` | 4×4 STL-to-robot transform from ICP |
| `data/cone_touch_poses.csv` | Side strip touch poses (with strip index and tilt per pose) |
| `figures/` | Plot outputs from the CAD/pose pipeline (steps 1–6) |
| `pyForceDAQ/cone_data/` | `sync_cone_data.sh` landing spot for recordings synced from the DAQ PC (gitignored) |
| `ur5_tactile_data/<egg>/` | Per-egg recordings (`<ts>_trajectory.csv`, `<ts>_presses.csv`) and analysis outputs |
| `cad_env/` | Python virtual environment |

---

## Key Parameters

Defined in `pose_utils.py` and the generator/analysis scripts:

| Parameter | Value | Location |
|---|---|---|
| Tool tip offset | `[0, 0, 0.086]` m | `pose_utils.py` |
| Start clearance | `0.03` m (30 mm above apex) | `pose_utils.py` |
| Default start orientation | `[-2.2, 2.2, 0.0]` rad | `pose_utils.py` |
| Approach stand-off | `0.015` m | `pose_utils.py` |
| Press depth | `0.015` m | `pose_utils.py` |
| Orientation tilt (off-normal) | `7°` apex band → `14°` lowest band (`MIN/MAX_ORIENTATION_TILT_DEG`) | `pose_utils.py` |
| Sim transit speed / accel (joint) | `V_sim = 3` rad/s, `A_sim = 8` rad/s² | `pose_utils.py` |
| Real transit speed / accel (joint), ATI | `ATI_V_real = 0.7` rad/s, `ATI_A_real = 0.35` rad/s² — the unprefixed `V_real`/`A_real` default to these | `pose_utils.py` |
| Real transit speed / accel (joint), XELA | `XELA_V_real = 0.1` rad/s, `XELA_A_real = 0.2` rad/s² — larger, heavier tool with a cable | `pose_utils.py` |
| Sim approach (contact) speed / accel | `V_approach_sim = 1` m/s, `A_approach_sim = 2.5` m/s² | `pose_utils.py` |
| Real approach (contact) speed / accel | `V_approach_real = 0.1` m/s, `A_approach_real = 0.2` m/s² | `pose_utils.py` |
| Lift before return to start | `SAFE_LIFT_M = 0.06` m (base +Z) | `execution/run_side_strip_poses.py` |
| Settle pause (sim / real) | `0.1` s / `1` s | `execution/run_side_strip_poses.py` |
| Number of strips | `NUM_STRIPS = 24` — tunable, evenly around the cone | `pose_generation/generate_side_strip_poses.py` |
| Points per strip | `NUM_POINTS = 12` — tunable, apex → lower bound | `pose_generation/generate_side_strip_poses.py` |
| Side strip lower bound | `MIN_HEIGHT_FRACTION = 0.45` — tunable, fraction from base | `pose_generation/generate_side_strip_poses.py` |
| Press detect threshold | `PRESS_ON_N = 0.3` N on / `PRESS_OFF_N = 0.15` N off, on `Fmag` | `pyForceDAQ/record_cone_press.py` |
| Press-off debounce | `PRESS_OFF_DEBOUNCE_S = 0.5` s | `pyForceDAQ/record_cone_press.py` |
| Press refractory window | `PRESS_REFRACTORY_S = 1.5` s (keep below the shortest press-to-press gap) | `pyForceDAQ/record_cone_press.py` |
| Press hold-speed gate | `PRESS_HOLD_SPEED_MS = 0.01` m/s — a candidate press needs an in-contact sample at/below this speed to count | `pyForceDAQ/record_cone_press.py` |
| DAQ sample rate | `SENSOR_RATE = 500` Hz | `pyForceDAQ/record_cone_press.py` |
| Force log rate | `125` Hz (`LOOP_HZ`) | `pyForceDAQ/record_cone_press.py` |
| Force sensor | `FT12876` (Nano17) | `pyForceDAQ/record_cone_press.py` |
| Near-miss report threshold | `NEAR_MISS_N = 0.10` N — contact peaking between this and `PRESS_ON_N` is reported as `[MISSED]` rather than ignored | `pyForceDAQ/record_cone_press.py` |
| XELA press target | `TARGET_TOTAL_COUNTS = 5000` (total over all 16 taxels) | `Xela_sensor/palpation/xela_palpation.py` |
| XELA per-taxel abort | `MAX_PEAK_COUNTS = 2200` | `Xela_sensor/palpation/xela_palpation.py` |
| XELA travel caps | `20` mm approach, `18` mm press | `Xela_sensor/palpation/xela_palpation.py` |
| XELA press speeds | `8` mm/s approach, `2` mm/s press (continuous, sensor-interrupted) | `Xela_sensor/palpation/xela_palpation.py` |
| XELA baseline settle | `SETTLE_S = 3.0` s — the pad sits ~35% of the press amplitude *below* its pre-press level afterwards and is still ~15% low a minute later | `Xela_sensor/palpation/xela_palpation.py` |
| XELA pose spacing / height floor | `12` mm spacing (~53% pad overlap), `MIN_HEIGHT_FRACTION = 0.65` | `Xela_sensor/palpation/make_xela_poses.py` |
| Live plot on/off | `LIVE_PLOT = True` | `pyForceDAQ/record_cone_press.py` |
| Live plot auto-open browser locally | `LIVE_PLOT_AUTO_OPEN = False` | `pyForceDAQ/record_cone_press.py` |
| Live plot HTTP port | `LIVE_PLOT_PORT = 8765` (first free at/after this) | `pyForceDAQ/record_cone_press.py` |
| Live plot re-render / poll interval | `LIVE_PLOT_REFRESH_S = 0.5` s | `pyForceDAQ/record_cone_press.py` |
| Live plot trajectory decimation / window | `LIVE_PLOT_DECIMATE = 5`, `LIVE_PLOT_MAX_POINTS = 3000` | `pyForceDAQ/record_cone_press.py` |
| Live plot cone surface point cap | `LIVE_PLOT_SURFACE_MAX_POINTS = 800` | `pyForceDAQ/record_cone_press.py` |

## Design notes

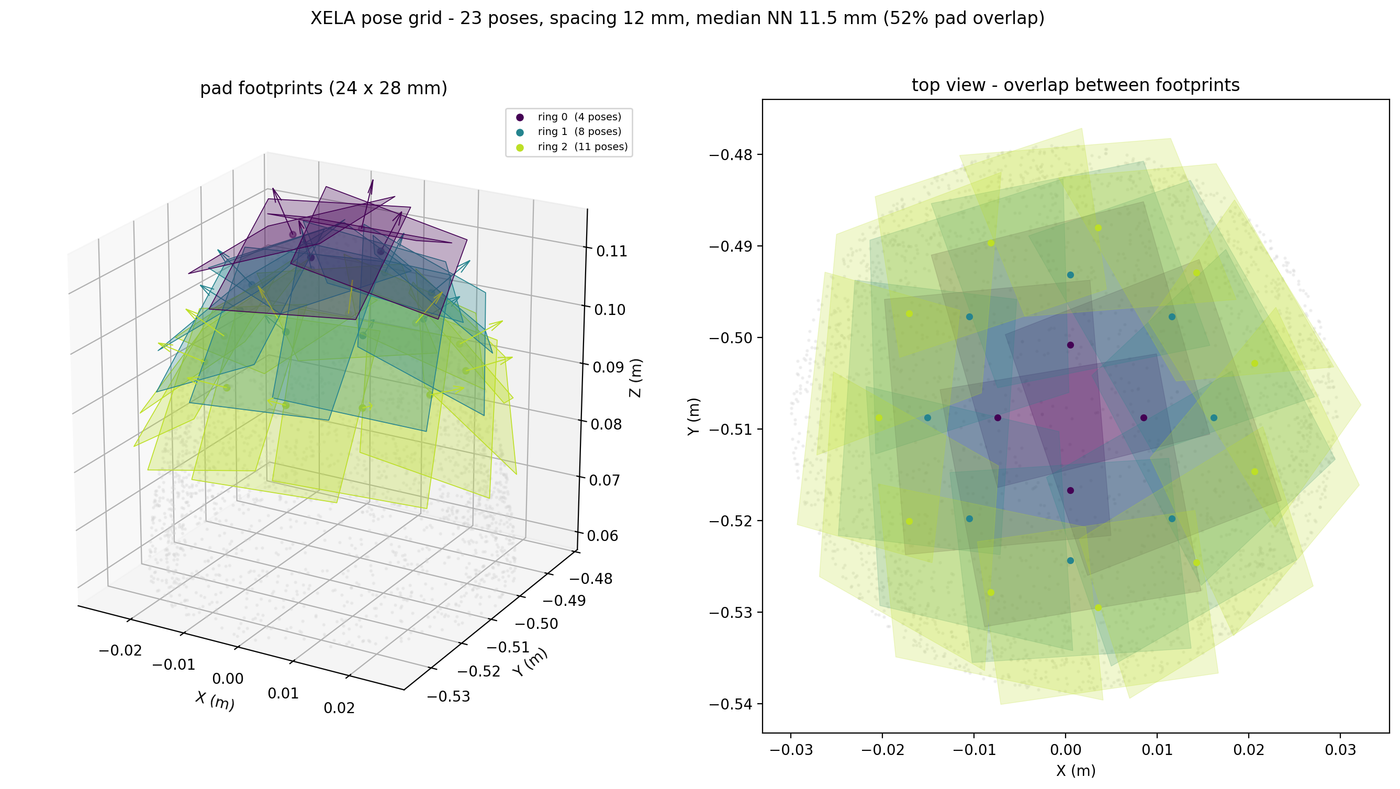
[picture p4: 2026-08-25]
figures/xela_poses.png

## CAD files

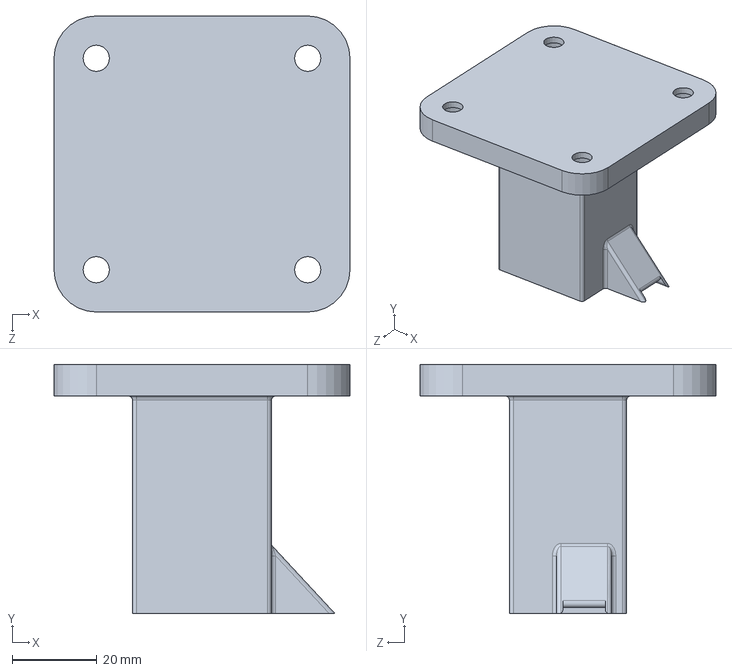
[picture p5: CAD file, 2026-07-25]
data/xela_sensor_breadboard_mount.SLDPRT
70.0 x 59.0 x 70.0 mm

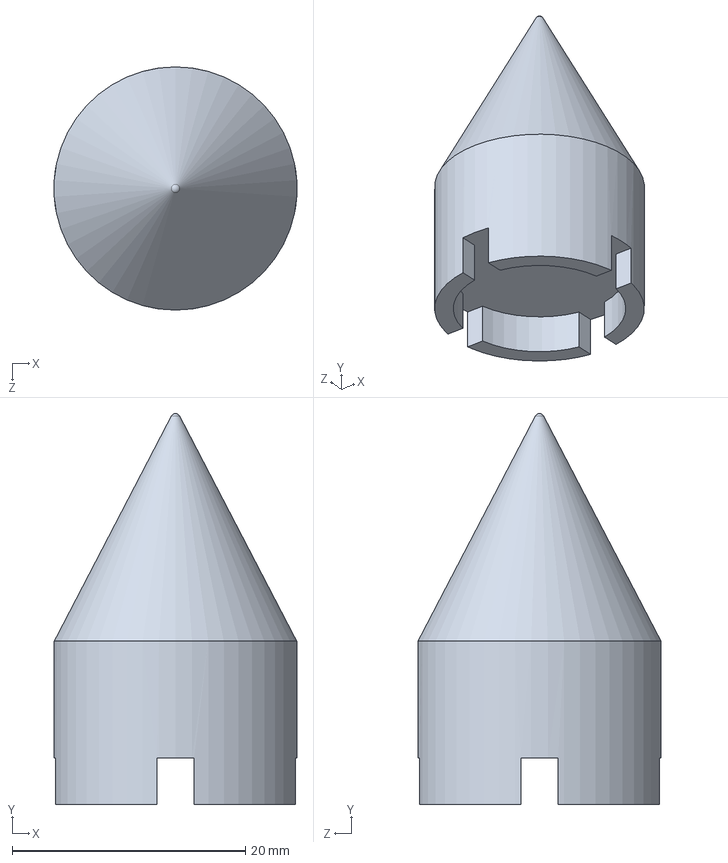
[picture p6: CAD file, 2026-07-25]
data/tip_touch_li_0.7.SLDPRT
20.8 x 33.5 x 20.9 mm

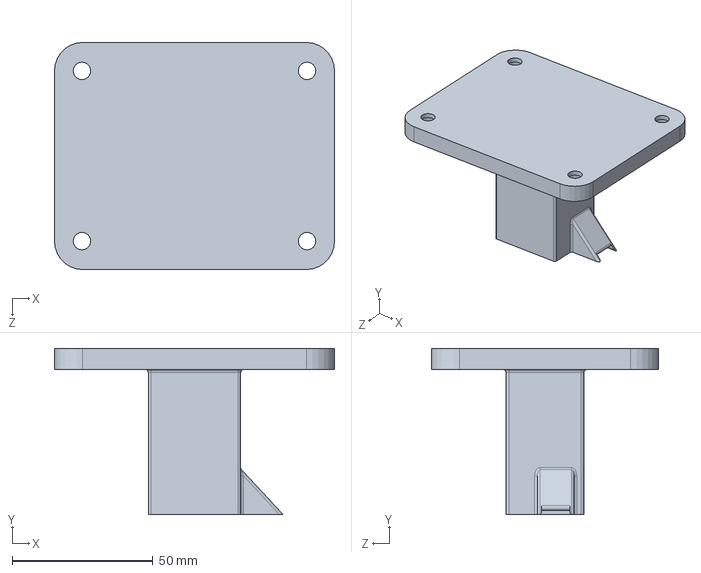
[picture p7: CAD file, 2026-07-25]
data/xela_sensor_mounted.SLDPRT
99.5 x 59.0 x 80.7 mm

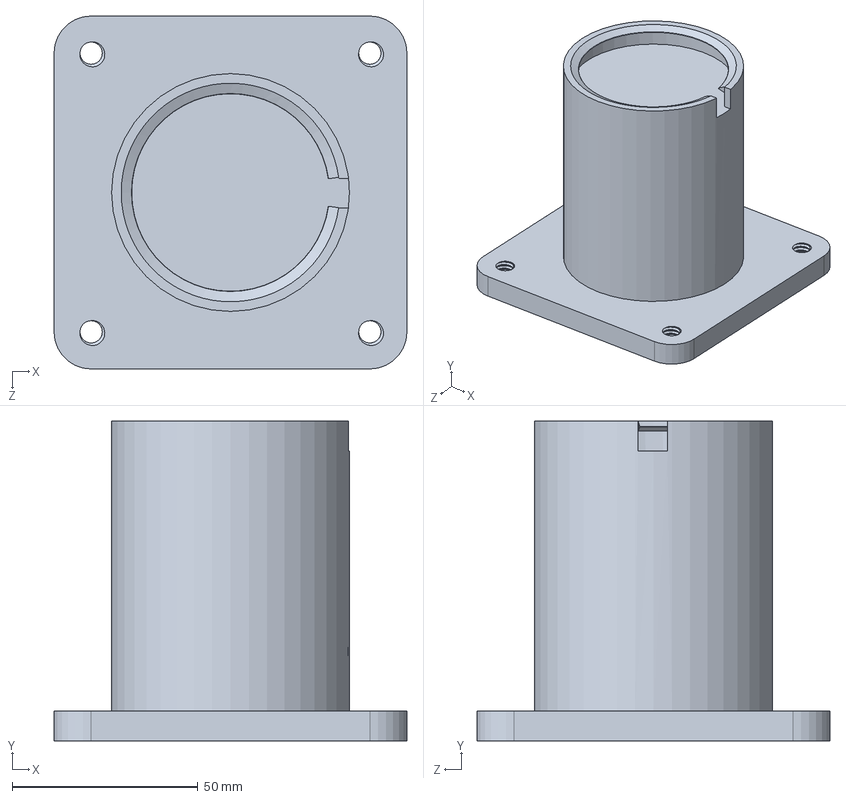
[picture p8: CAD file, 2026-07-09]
data/egg_holder_4_revolvehole-3mm.SLDPRT
95.0 x 86.0 x 95.0 mm

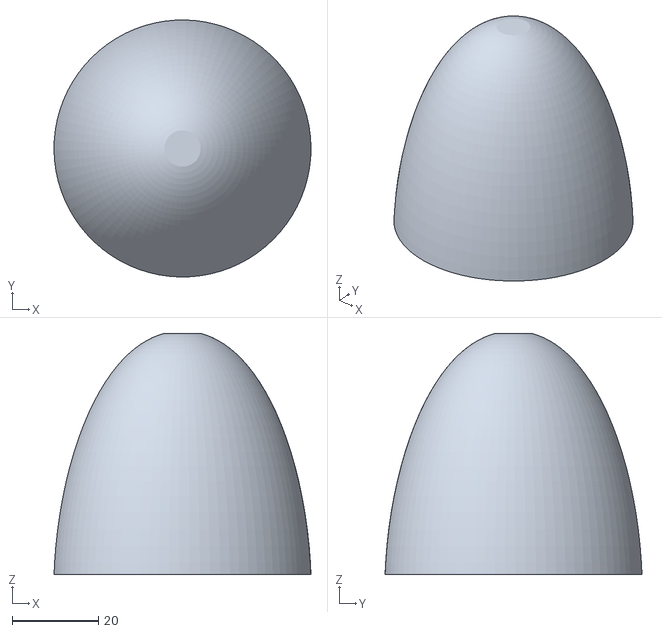
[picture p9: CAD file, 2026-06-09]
data/cone.STL
59.7 x 59.7 x 56.0

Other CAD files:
data/egg_holder_4_revolvehole-3mm.STL
data/tip_touch_li_0.7.STL
data/xela_sensor_breadboard_mount.STL
data/xela_sensor_mounted.STL

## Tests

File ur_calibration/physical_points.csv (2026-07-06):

x_tcp | y_tcp | z_tcp | rx | ry | rz | x | y | z
-0.001 | -0.512 | 0.1973 | -2.2 | 2.2 | 0.0 | 0.000843683774197622 | -0.5101563162258024 | 0.11133953431791148
0.001 | -0.4385 | 0.16455 | 1.8255 | -1.7777 | 0.7083 | 0.0033164758155253085 | -0.49588988581254945 | 0.10054191499334934
0.0059180000000000005 | -0.423997 | 0.145917 | 1.717913 | -1.668565 | 0.827211 | 0.008235387254117127 | -0.4909689724340349 | 0.09201538013000604
0.0058920000000000005 | -0.413011 | 0.12477200000000001 | 1.605287 | -1.554902 | 0.937198 | 0.008203848440635307 | -0.4879026974337972 | 0.08255957277445294
0.000997 | -0.584998 | 0.167182 | -1.744302 | 1.759488 | 0.709544 | 0.002838924360074848 | -0.5240388974500914 | 0.10654706674398429
0.000994 | -0.600985 | 0.14544900000000002 | -1.626629 | 1.644705 | 0.837087 | 0.002841438708172638 | -0.5303999710388007 | 0.09635377969530853
0.000962 | -0.613979 | 0.120259 | -1.475588 | 1.496788 | 0.979477 | 0.0028128451795100718 | -0.5344671908255489 | 0.08754132016283636
0.084104 | -0.512977 | 0.155417 | 1.67655 | -1.694348 | -0.838145 | 0.016443874602157585 | -0.5111403706196536 | 0.10236293112995494
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

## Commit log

2026-06-10 made cosmetic changes so directory would be better organised
    [random_upper_touch_poses.csv]
2026-06-10 added pyForceDAQ folder for data acquistion
    [spiral_points.csv]
2026-06-10 added scripts for generating and running the side strip poses
    [side_strip_touch_poses.csv]
2026-06-10 change in figures, .csv
    [side_strip_touch_poses.csv, surface_points.csv, surface_points_base.csv]
2026-06-11 returned physical_points.csv to directory
    [physical_points.csv]
2026-06-19 reorganized directory
    [cone.STL, physical_points.csv, pyvenv.cfg]
2026-06-23 adjusted to new platform
    [physical_points.csv]
2026-07-01 streaming part and sldprt file
    [egg_holder_3_revolvehole.SLDPRT]
2026-07-06 new functions, recalibrated ICP
    [physical_points.csv]
2026-07-06 calibration update
2026-07-09 major changes
    [2026-07-09_14-41-01_presses.csv, 2026-07-09_15-25-24_presses.csv, 2026-07-09_16-02-27_presses.csv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]
2026-07-23 added xela sensor
2026-07-25 minor update
    [egg_holder_4_revolvehole-3mm.STL, tip_touch_li_0.7.SLDPRT, tip_touch_li_0.7.STL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]
2026-07-25 low force calibration
2026-07-28 new method of calibration
